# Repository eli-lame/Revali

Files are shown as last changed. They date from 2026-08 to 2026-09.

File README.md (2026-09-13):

# Revali

Flight controller firmware for a **hopcopter** — a quadrotor with a passive
spring-loaded telescopic leg that lets it hop along the ground instead of
flying continuously. Hopping is dramatically more power-efficient than hover,
because thrust is applied in short bursts at launch rather than held constantly.

The design replicates the Hopcopter described in *Science Robotics* (City
University of Hong Kong / HKUST): the leg is entirely passive — rubber bands
and a sliding rod — and **all** control authority comes from the four rotors.
The firmware's job is to keep the vehicle upright and steer it by tilting,
whether it is hovering, ballistic, or compressing on the ground.

## Hardware

| Role | Part |
|---|---|
| Vehicle MCU | ESP32-WROOM |
| IMU | SparkFun ICM-20948 (accel + gyro + mag) |
| Height / ground contact | 2× VL53L0X ToF, both downward-facing, spaced apart |
| Propulsion | 4× brushless motors + ESCs, quad-X layout |
| Controller MCU | ESP32-WROOM (offboard, USB-powered from the laptop) |
| Input (reference) | 1× SparkFun analog joystick (VCC, XOUT, YOUT, SEL, GND) |
| Input (optional) | DS4 / SCUF gamepad paired to the offboard ESP32 (Bluepad32) |
| Link | ESP-NOW |
| Ground station | Browser dashboard, fed over the controller's USB cable |

The controller sends **intent** — desired roll / pitch / yaw-rate / climb-rate
— never raw throttle; altitude and hop energy are managed onboard, and the
vehicle clamps every command to its own limits. Because the wire packet carries
intent, the vehicle is **controller-agnostic**: the reference one-stick joystick
(which cycles what its two axes mean) and an optional two-stick DS4/SCUF gamepad
(which needs no cycling) feed the identical packet. See
[flight_modes.md](docs/flight_modes.md) and
[communication.md](docs/communication.md).

## Repository layout

```
firmware/     PlatformIO project — vehicle (flight controller)
controller/   PlatformIO project — offboard transmitter
shared/       Link protocol definitions included by both projects
groundstation/ Host bridge + browser dashboard
docs/         Design documents
tools/        Host-side scripts (log decoding, PID tuning, plotting)
```

## Documentation

Start with [architecture.md](docs/architecture.md), then
[hardware.md](docs/hardware.md).

| Doc | Covers |
|---|---|
| [architecture.md](docs/architecture.md) | Module boundaries and data flow |
| [hardware.md](docs/hardware.md) | Wiring, buses, pin map, the VL53L0X address problem |
| [hardware_roadmap.md](docs/hardware_roadmap.md) | Board architecture, the 4-in-1 stack, staged path to a custom FC |
| [data_model.md](docs/data_model.md) | The structs every module shares |
| [estimator.md](docs/estimator.md) | Attitude fusion and dual-ToF height |
| [control_loop.md](docs/control_loop.md) | Controller, mixer, motor output |
| [flight_modes.md](docs/flight_modes.md) | State machine; per-controller intent resolution |
| [hop_mode.md](docs/hop_mode.md) | Hop phase machine and thrust profile |
| [communication.md](docs/communication.md) | ESP-NOW link, packet format, failsafe |
| [ground_station.md](docs/ground_station.md) | Browser dashboard for live telemetry and health |
| [safety.md](docs/safety.md) | Every failsafe and its trip condition |
| [scheduler.md](docs/scheduler.md) | Task rates and timing budget |
| [current_devtasks.md](docs/current_devtasks.md) | **The build order — start here to work** |

## Status

Early. The shared data contracts and estimator interfaces exist and compile;
no driver, controller, or link is implemented yet. See
[current_devtasks.md](docs/current_devtasks.md).

## Building

```bash
cd firmware && pio run -t upload && pio device monitor
```

## License

See [LICENSE](LICENSE).

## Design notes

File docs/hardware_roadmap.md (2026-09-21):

# Hardware roadmap

[hardware.md](hardware.md) describes the vehicle as it is wired **today**: an
ESP32-WROOM devkit, a SparkFun ICM-20948 breakout, two VL53L0X breakouts, four
discrete 30 A ESCs, and a buck module, all joined by roughly fifty wires. That
arrangement is correct and it works. It is also most of the vehicle's dry mass
that is not a motor, and on a machine whose entire premise is that launch
energy is scarce, that matters.

This document records how the electronics get from there to a custom board, in
what order, and — more importantly — which things deliberately do **not** get
integrated. It is the design-rationale companion to `hardware.md`: that file
says what to wire, this one says why the board looks the way it does.

---

## The central decision: two boards, not one

The intuitive move is a single custom board carrying everything — MCU, IMU,
buck, battery sense, and the motor power distribution. **Do not do that.** The
vehicle gets two boards:

```
        +------------------------------+
        |  REVALI FC  (custom)         |  MCU, IMU, 5 V buck, 3V3 LDO,
        |  30.5 x 30.5 mounting        |  battery divider, USB, connectors
        +--------------+---------------+
                       |  8-pin JST-SH ribbon
                       |  VBAT . GND . S1-S4 . current sense . telemetry
        +--------------+---------------+
        |  4-IN-1 ESC  (off the shelf) |  four ESCs + power distribution,
        |  30.5 x 30.5, 3-6S, 45-60 A  |  battery leads and 12 phase wires
        +------------------------------+
```

The 4-in-1 ESC **is** the power distribution board. It is not an extra
component sitting alongside a PDB; it is the PDB, with the four speed
controllers already integrated, the bulk capacitor already placed next to the
FETs, and the current shunt already installed.

### Why the motor current does not come onto our board

It is tempting to reason that since VBAT is already present for the buck, the
motor rails may as well come too. The voltage is the same. The current is not:

| Path | Current at 14.8 V |
|---|---|
| Buck feed (5 V @ 1 A out, ~85 % efficient) | **~0.4 A** |
| Four ESCs at peak | **~120 A** |

That is a factor of three hundred, and it changes the problem completely.

**Copper.** At 2 oz, carrying 120 A needs roughly **44 mm of copper width**
even allowing a punishing 45 °C temperature rise — wider than the whole board.
A 60 A launch burst still needs ~17 mm, per path, in four directions. This is
why commercial PDBs are effectively busbars: solid pours with the soldermask
removed so solder can be flooded on to add metal by hand.

**di/dt.** ESCs switch at 24–48 kHz with sharp edges, and each one needs a
low-ESR capacitor within about 5–10 mm of its power pads. Long pours from a
central battery pad out to four corner ESCs add loop inductance, and that
inductance produces voltage spikes that destroy FETs. It is the most common way
a home-made PDB kills bought ESCs — and it kills them in a way that looks like
the ESCs were faulty.

**Ground bounce.** 120 A of pulsed 30 kHz current sharing copper with a 3.3 V
SPI bus and a gyro read at 1 kHz is a noise problem that commercial designs
avoid by putting power and flight control on separate boards.

**Thermal.** 120 A through even 1 mΩ of copper is 14 W. That board becomes a
heater sitting under the IMU, and gyro bias drifts with temperature.

**Blast radius.** Lift a pad soldering 14 AWG battery leads and you have
destroyed the MCU, the IMU and the buck along with it. Separate boards mean a
dead power stage is a thirty-dollar replacement, not a respin and a three-week
wait.

### It is also the lighter option

A custom PDB does not remove the twelve motor phase wires, and it leaves four
ESC bricks on the arms. A 4-in-1 removes the bricks and shortens the phase
wires to a couple of centimetres each.

| | Discrete ESCs + custom PDB | 4-in-1 |
|---|---|---|
| ESC mass | ~7 g × 4 = 28 g | 12–14 g total |
| PDB mass | 8–12 g (2 oz copper) | 0 — it is the PDB |
| Phase wire | full arm length × 12 | ~2 cm × 12 |
| FC ↔ power interface | 16 wires | one ribbon |

Roughly **25–30 g saved**, which is the thing we were trying to buy in the
first place.

### What our board keeps

Everything that made a custom board attractive, minus the copper:

- MCU and IMU as chips/modules rather than breakouts
- 5 V buck **on our board**, fed from VBAT up the ribbon
- Battery divider tapping **raw** VBAT before regulation, as
  [hardware.md](hardware.md) requires — the buck hides the sag the failsafe
  needs to see
- USB, status LED, buzzer, connectors

Do not take 5 V from an ESC BEC even when one is present. `hardware.md` already
states the rule — motor current transients on a shared 5 V rail cause brownouts
that look exactly like firmware crashes — and a BEC on the ESC board sits in
the middle of the switching it would need to be immune to.

### The ESC interface — Skystars KO50A

The 4-in-1 selected for Stage 1. Confirmed specifications:

| | |
|---|---|
| Board / mounting | 41 × 46 mm, 30.5 × 30.5 M3, soft-mounts included |
| Weight | 13.3 g |
| MCU / firmware | BB21 @ 48 MHz, BLHeli_S 16.x, DShot150/300/600 |
| Pack | 3–6 S (silkscreened 25 V — **stay on 4 S**, 6 S at full charge is 25.2 V) |
| Current sensor | Yes |
| **BEC** | **No** — the 5 V rail is ours to generate |
| In the box | ESC, 8-pin cable, bulk capacitor |

The 8-pin JST-SH pinout, confirmed against the hardware:

| Pin | Signal | Goes to |
|---|---|---|
| 1 | GND | board ground |
| 2 | **BAT** | raw pack voltage → buck input and battery divider, nothing else |
| 3 | S1 | motor 1 signal |
| 4 | S2 | motor 2 signal |
| 5 | S3 | motor 3 signal |
| 6 | S4 | motor 4 signal |
| 7 | **NC** | not connected — no separate telemetry line on this board |
| 8 | CURR | analog current-sense output → ADC1 |

Two things follow. **BAT is raw pack voltage**, 16.8 V at full charge on 4 S — it
goes to the buck input and the divider and nowhere else. In particular it must
never reach the devkit's `VIN` pin, whose onboard AMS1117 is rated to roughly
15 V.

And pin 7 being NC means there is **no separate ESC telemetry wire**. That does
not rule out RPM feedback: bidirectional DShot returns telemetry on the signal
line itself, so flashing Bluejay onto the BLHeli_S firmware gets RPM back over
S1–S4 with no extra conductor.

---

## Power topology and the on/off switch

There is exactly **one battery connection in the vehicle**: the XT60 solders to
the 4-in-1's battery pads, alongside the bulk capacitor. Nothing high-current
ever reaches our board.

```
  LiPo ──XT60──► 4-IN-1 battery pads (B+ / B-)
                    |
                    +--> internally: the four ESCs
                    |
                    +--> 8-pin ribbon: BAT, GND --> REVALI FC
                                                      |
                                                      +--> [FC power switch]
                                                             |
                                                             +--> buck --> 5 V --> devkit VIN
                                                             +--> 100k/22k divider --> ADC1
```

### There is no switch in the motor path, and there will not be one

The v1 prototype schematic placed a screw terminal in series with battery
positive, annotated "switch goes here." That is deleted, for two reasons.

**A switch there carries full motor current** — roughly 120 A peak. A switch
genuinely rated for that is a contactor: heavier than everything else on the
board put together, and it inserts contact resistance into the highest-current
path in the vehicle.

**Moving it to the FC does not achieve the same thing.** A switch that only
cuts our board's BAT feed leaves the ESCs fully powered from the pack. This is
not especially *dangerous* — DShot frames are checksummed and BLHeli will not
arm without a valid throttle-low signal, so floating inputs on an unpowered FC
do not spin motors — but it disconnects nothing that matters, while looking
like it does.

**The battery connector is the disconnect.** No FPV multirotor has a power
switch. Unplugging the XT60 is the only guaranteed-safe state, and an
anti-spark XT60 handles the inrush spark from the ESC's bulk capacitor.

### Power states

| State | How to get it | Motors |
|---|---|---|
| Fully off | XT60 unplugged | dead |
| FC only — bench work, flashing | USB connected, **no pack** | physically dead |
| Full system, safe | XT60 plugged in, firmware disarmed | live bus, held at disarmed value |
| Full system, armed | Safety arms — see [safety.md](safety.md) | live |

The second row is the important one: the devkit's USB gives a better
"controller running, motors physically dead" mode than any switch, for free.
That is the normal bring-up configuration.

### If a switch is fitted anyway

A small switch in the FC's BAT feed — downstream of the ribbon entry, upstream
of both the buck and the divider, so the whole board goes dead with no standby
drain — is a legitimate bring-up convenience: it power-cycles the FC for
reflashing without unplugging the pack. That path carries ~0.4 A at 16.8 V, so
any slide switch or even a removable 2-pin jumper is sufficient.

Label it in the schematic as **`FC POWER — NOT A SAFETY DISCONNECT`**. It is
not one, and in three months that label is the only thing that will say so.

---

## The ToF sensors stay off the board

This is a real constraint, not a convenience. [hardware.md](hardware.md)
requires each VL53L0X to sit at a recorded position in the body frame, with a
measured baseline between them, a known offset from the CG, and a clear ~25°
cone below it containing no part of the airframe. Front-left and rear-right of
the CG, spaced as widely as the frame allows — the baseline is what turns their
difference into a ground slope, and a short baseline makes the estimate noisy.

A sensor soldered to a 36 mm board is at the CG with a baseline of a few
centimetres. The FC gets a **4-pin JST-SH connector per sensor**; the sensors
mount where the geometry needs them.

The IMU is the opposite case: it belongs at the CG, on the board, soft-mounted.

---

## Staging

Two goals are in tension here: learning PCB design, and finishing the vehicle.
They conflict because a board revision is slow — about two weeks to design, two
to fabricate and ship, and first boards usually need one respin. That is
roughly seven weeks before working hardware exists. **If the firmware is
blocked behind the board, that cost lands on the whole project.**

So the tracks are kept independent. Each stage below flies on its own.

### Stage 0 — current: breadboard (done)

WROOM devkit, ICM-20948, two VL53L0X, discrete ESCs. Ugly, working. Firmware
development proceeds here and is never blocked by the board.

### Stage 1 — 4-in-1 ESC swap

Replace the four discrete ESCs and their harness with one 4-in-1. No PCB work.
This alone removes most of the wiring mass and validates the ribbon interface
the custom board will mate to.

### Stage 2 — carrier board

A **2-layer, hand-solderable** board on the 30.5 × 30.5 mounting pattern,
carrying the existing devkit in a 2.54 mm socket, the breakout modules, the
regulator, the battery divider, and the connectors. No bare chips, no fine
pitch, nothing that cannot be reworked with an iron.

**Built and routed; outline came out at 58 × 88 mm.** Bigger than a
conventional FC because a 30-pin devkit is 52 × 25 mm on its own, so the board
overhangs the ESC on every side. Acceptable at this stage — weight optimisation
is Stage 3's job, and it gets there by dropping the devkit for a bare module.

Ground is a **single plane on `B.Cu`** with no top pour. The top layer routed
densely enough that a pour filled only in patches and was not reaching several
of the pads it was meant to serve. Every ground connection is explicit instead:
through-hole pads through their own barrels, every SMD ground pad through a
short wide stub to its own via. That is best practice regardless of whether a
top pour exists — the return current from a decoupling capacitor wants the
shortest loop into the plane, not a wander across the top layer looking for a
via.

Full net-by-net spec, BOM and bring-up order:
[stage2-carrier/README.md](https://github.com/eli-lame/Genli/blob/main/stage2-carrier/README.md).

This stage is easy to skip and should not be. It is cheap and quick, it teaches
the entire pipeline end to end — schematic, footprints, layout, DRC, Gerbers,
ordering, assembly, bring-up — with almost nothing at stake, and every
schematic block and footprint it produces is reused by Stage 3. It also solves
the wiring problem immediately: roughly fifty wires become about six.

### Stage 3 — integrated FC

4-layer, assembled by the fab, bare module + IMU chip + integrated buck +
USB-C. Designed as a **drop-in replacement** for Stage 2: same pin functions,
same connector positions, same firmware binary.

Built this way, Stage 3 is optional. If it works, it goes in the vehicle. If it
does not, the vehicle still flies on Stage 2 hardware, and the project is not
hostage to a PCB revision.

---

## Link: ESP-NOW now, ELRS later

The eventual target is the standard split used by serious builds:

- **Control in** — ExpressLRS receiver over CRSF on a UART. Sub-5 ms, real link
  statistics, proper failsafe, telemetry on the return path.
- **Telemetry out** — BLE or USB to the ground station.

We are **not** switching yet. ESP-NOW works today, the vehicle's link layer is
already built around it, and Stages 1–3 already change the power architecture,
the board, and the mechanical layout. Changing the radio at the same time means
that when something misbehaves there is no way to tell which change caused it.

Note that BLE is not a candidate for the *control* link regardless — its
minimum connection interval is 7.5 ms with real jitter, and it is not designed
for deterministic control. BLE is for telemetry and configuration only, which
is exactly how commercial flight controllers use it.

**The one thing to do now:** put a 4-pin JST-SH footprint (5 V, GND, TX, RX) on
a spare UART on both the Stage 2 and Stage 3 boards, wired and unpopulated.
Four pads and about thirty cents. With them, adopting ELRS later is a firmware
change. Without them, it is a board respin.

When the switch does happen, two consequences follow. The `controller/` project
leaves the critical path — CRSF carries the same intent the wire protocol in
[communication.md](communication.md) already defines, so the vehicle stays
controller-agnostic and the custom transmitter becomes an optional input rather
than a dependency. And [ground_station.md](ground_station.md) loses its current
transport: the dashboard is fed over the controller's USB cable today, and
would instead talk to the vehicle directly.

---

## Part selection

| Block | Part | Why |
|---|---|---|
| 4-in-1 ESC | **Skystars KO50A** — 30.5 × 30.5, 3–6 S, 50 A | Ordered. Full interface above |
| 5 V regulator | **Pololu D24V10F5** — 5.1–36 V in, 5 V @ 1 A, 12.7 × 17.8 mm | Ordered. Fixed output, solder flat, 33 µF+ electrolytic at VIN per Pololu's lead-length warning |
| MCU | ESP32-WROOM-32E (bare module) | Same silicon as the devkit — zero firmware port. Castellated and hand-solderable |
| MCU (upgrade) | ESP32-S3-WROOM-1 | Native USB and BLE 5. Only worth it once BLE telemetry is wanted; verify the footprint difference before assuming drop-in |
| IMU | **ICM-42688-P** | Much better anti-alias filtering than the ICM-20948, which matters a great deal on a vehicle that repeatedly slams into the ground. Drop the magnetometer — it is useless indoors beside 120 A of motor current |
| ToF | **VL53L1X** | Programmable region of interest, which directly attacks the wide-cone problem documented in [hardware.md](hardware.md). VL53L5CX (8 × 8 zones) if off-axis rejection needs to be done properly |
| 5 V rail (Stage 3) | Discrete synchronous buck IC rated **≥ 36 V input** | Replaces the module once switching layout is worth learning on its own |
| 3.3 V rail | Stage 2: the devkit's onboard AMS1117 (~50 mA of sensors — ample). Stage 3: an LDO from 5 V, separate feed for the IMU | Low noise for the gyro |
| Protection | TVS on VBAT + low-ESR bulk at the pads | Non-negotiable beside brushless motors |

**On ESC voltage rating:** a "6–18 V" (2–4 S) part is not acceptable here. A 4 S
pack is 16.8 V at full charge, leaving 1.2 V of margin, and ESCs generate
regenerative spikes when throttle drops sharply. On a hopper that is not an
edge case — it is every single cycle: full-send launch, immediate cut,
ballistic phase, catch on landing. Specify 3–6 S (≈26 V, 35 V capacitors).

Choose every part against the fab's assembly library **before** finalising the
schematic. On a board this size, hand-soldering an LGA IMU is miserable; part
availability will constrain the BOM more than preference does.

---

## Rules specific to a hopping vehicle

This airframe's purpose is repeated hard impact, which changes the board rules:

- No tall electrolytics standing unsupported. Solid polymer capacitors, and
  stake anything with mass.
- Soft-mount the board on gummies or TPU standoffs. A rigidly-mounted gyro on
  this vehicle sees impact spikes that alias into the attitude estimate.
- Prefer solder pads and staked wires anywhere a connector could walk out of
  its housing under shock.
- Conformal coat after bring-up.
- Buy spares. Two ESCs, a spare MCU, and many propellers — this machine is
  designed to hit the ground.

---

## Defects in the v1 prototype schematic

Recorded here because they are cheap to fix now and expensive to find during
bring-up. That board has not been fabricated and is superseded by the staging
above, but the same nets carry forward.

**ESC signal numbering is reversed relative to the pin map.** The schematic
assigns `ESC1_SIG → GPIO14, ESC2 → GPIO27, ESC3 → GPIO33, ESC4 → GPIO32`. The
pin map in [hardware.md](hardware.md) assigns Motor 1 (front-left) to GPIO 32,
Motor 2 to 33, Motor 3 to 27 and Motor 4 to 14 — so schematic `ESC1` is the pin
map's Motor 4, and the ordering is inverted end to end. The mixer would drive
the wrong physical motor for every roll and pitch term. Combined with the
unresolved yaw-sign question from the pusher-prop mounting, this would be very
difficult to diagnose in the air. One of the two must change;
[hardware.md](hardware.md) is the source of truth.

**Battery sense is absent.** GPIO 34, 35, 36 and 39 are all marked no-connect.
The 100 kΩ / 22 kΩ divider specified in `hardware.md` is not on the board, so
`warn_voltage`, `land_voltage` and `critical_voltage` in [safety.md](safety.md)
have no input and the low-battery failsafe cannot function. Two resistors and a
capacitor on a board that already carries VBAT.

**No bulk capacitance, TVS, or reverse-polarity protection on VBAT.**
Acceptable while every power component is a module with its own input caps; it
becomes ours the moment the buck is on our board.

---

## Open decisions

- **Frame geometry.** Motor-to-motor diagonal, and confirmation that the leg's
  travel clears a centre-mounted stack. The leg moves below the frame and does
  not pass through it, so a centred stack is expected to be fine — this needs
  checking against the actual frame before layout.
- **MCU for Stage 3** — WROOM-32E (no port, no BLE) or S3 (port, BLE).
  Deferred until the BLE telemetry path is actually wanted.
- **Current sensing.** Deferred, not dropped. The KO50A exposes `CURR` on pin 8,
  and it would give joules-per-hop directly — the number that validates the
  efficiency premise this whole vehicle is built on. Stage 2 routes the trace
  and leaves the resistor unpopulated, so enabling it later costs one 0805 part
  plus a calibration. Two things are unresolved until then: the full-scale
  output voltage, which Skystars does not publish and which must be measured
  before anything is connected to a GPIO, and the volts-per-amp scale factor,
  which needs a meter.

Settled since this document was written: the KiCad projects live in a separate
repository, **[eli-lame/Genli](https://github.com/eli-lame/Genli)** — boards
only, one KiCad project per board, with v1 archived there as `v1-prototype/`
and the current work in `stage2-carrier/`. Its README carries the layout and
library conventions.

Because the boards and the firmware are versioned separately, two rules apply.
This repository keeps [hardware.md](hardware.md) as the sole pin map and Genli
links to it rather than copying it. And when gerbers are generated, the Revali
commit the board was designed against is recorded in that board's
`production/` directory — it is the only link back from a fabricated board to
the pin map it assumed.

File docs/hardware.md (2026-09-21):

# Hardware

This file describes the vehicle as it is wired today, and is the source of
truth for the pin map. For where the electronics are *going* — the two-board
stack, why motor current stays off our board, and the staged path to a custom
FC — see [hardware_roadmap.md](hardware_roadmap.md).

## Vehicle

| Function | Part | Bus | Notes |
|---|---|---|---|
| MCU | ESP32-WROOM-32 | — | 240 MHz dual core |
| IMU | SparkFun ICM-20948 | **SPI** | accel + gyro @ 1 kHz, AK09916 mag @ ~100 Hz |
| Height A | VL53L0X | I2C | downward, front-left of CG |
| Height B | VL53L0X | I2C | downward, rear-right of CG |
| Motors | 4× brushless + ESC | LEDC/RMT | quad-X |
| Battery sense | resistor divider | ADC1 | ADC2 is unusable when WiFi/BT is active |

### Put the IMU on SPI, not I2C

The ICM-20948 breakout ships configured for Qwiic/I2C, but the control loop
needs it at 1 kHz. A 12-byte burst read at 400 kHz I2C costs roughly 700 µs of
bus time including addressing and ACKs — about **70 % of a 1 ms tick**, on a bus
also shared with two ranging sensors. That does not fit.

The same read over SPI at 7 MHz costs ~16 µs. Cut the `I2C`/`SPI` select jumper
on the SparkFun board and wire the SPI pads.

If you must stay on I2C for bring-up, run the loop at 500 Hz and put the ToF
pair on the second I2C peripheral. Treat that as temporary.

### Both VL53L0X sensors boot at address 0x29

This is the single most common way this build fails, so handle it first. Every
VL53L0X powers up at `0x29`, and the address is **not** persistent — it resets
on every power cycle. With both on one bus and no mitigation, you get a garbage
mixture of the two.

Wire each sensor's `XSHUT` pin to its own GPIO and sequence them at boot:

1. Drive **both** XSHUT low — both sensors held in reset, bus is clear.
2. Release XSHUT A. Wait ~2 ms for boot.
3. `setAddress(0x30)` on the sensor now answering at `0x29`.
4. Release XSHUT B. Wait ~2 ms. It comes up at `0x29`.
5. Verify: A responds at `0x30`, B at `0x29`, and a bus scan shows exactly two.

Never skip step 5 — a silent failure here reads one sensor twice and the
ground-plane estimate becomes meaningless while looking perfectly plausible.

XSHUT is **not** 5 V tolerant and has an internal pull-up; drive it from a GPIO
directly, and note that some breakouts need the pin driven low rather than
floated to actually hold reset.

**"Release" means high-impedance, not driven high.** On the carrier boards in
use here, XSHUT is pulled up by a 47 kΩ resistor to the breakout's internal
**2.8 V** rail — not to 3.3 V. So steps 2 and 4 above should set the GPIO back
to `INPUT` and let that resistor do the work. Driving the pin high instead
pushes a 3.3 V output into a 2.8 V rail through 47 kΩ; it works, but it
back-feeds current for no reason, and there is nothing to gain from it.

### The ToF breakout's VCC must be 3.3 V, never 5 V

The carrier boards have an onboard regulator and a MOSFET level shifter, so
`VIN` will happily accept 5 V — **do not give it 5 V.** The breakout's I2C
pull-up resistors (10 kΩ) connect to `VIN` itself, so the SDA and SCL lines
sit at whatever `VIN` is. Feed it 5 V and 5 V arrives on GPIO 21 and 22, which
are not 5 V tolerant.

This is why the pin map below says 3V3 for ToF VCC. It is not a convention;
it is the difference between a working bus and a damaged ESP32.

Those same 10 kΩ resistors are also why **no I2C pull-ups are needed on the
carrier board** — two breakouts on one bus put two 10 kΩ sets in parallel,
about 5 kΩ, which is already in the right range.

### Sensor geometry matters

Record the mounting position of each ToF in the body frame — the estimator
needs the baseline distance between them to turn their difference into a ground
slope, and needs each sensor's offset from the CG to correct for the height
change caused by tilt. Put these in `Parameters`, not in code comments.

Also record the **leg length**: the distance from each ToF to the foot when the
leg is fully extended. That number is the touchdown threshold.

### The VL53L0X measures a cone, not a point

It's a laser (VCSEL) source, but the optics spread it to a **~25° full field of
view** (~±12.5° off boresight), and the receiver's field of view is similarly
wide. The sensor reports the closest/strongest return **anywhere in that
cone**, not a single point straight down. Treat it like a narrow flashlight
beam, not a laser pointer.

The cone's footprint grows with distance:

```
footprint_diameter ≈ 2 × height × tan(12.5°)
```

At 100 mm of height that's already ~44 mm across. Anything within that
footprint — a wall, a bench edge, part of the airframe itself — can be
reported instead of the ground, with no flag that it happened; the reading
just looks like a slightly-wrong but plausible number.

This is a real mounting constraint, not just a bench-test nuisance:

- Each ToF needs a clear ~25° cone below it, out to at least the maximum
  expected hop height, with **nothing else on the airframe** — legs, arms,
  the other ToF's mount — inside that cone.
- During bring-up, test over open floor. A wall or bench edge within roughly
  a footprint-radius of the sensor's boresight, at your test height, will
  contaminate the reading.
- Task `[2.9]`–`[2.11]` in [current_devtasks.md](current_devtasks.md) should
  include physically checking this cone against the frame, not just measuring
  baseline/offset/leg-length in isolation.

### Pin map — vehicle ESP32

This is the pin assignment used throughout this project and by every doc that
references a GPIO number. Wire to it exactly. If you need to deviate (a board
revision, a part you're substituting), update this table first and treat every
other mention of these pins elsewhere in the docs as needing a matching update.

| Signal | GPIO | Wire color (suggested) | Notes |
|---|---|---|---|
| IMU SCLK | 23 | yellow | **not a VSPI default** — see the note below |
| IMU MISO | 25 | green | **not a VSPI default** |
| IMU MOSI | 19 | blue | **not a VSPI default** |
| IMU CS | 15 | orange | strapping pin, but its internal pull-up holds CS deasserted at boot — see below |
| IMU INT | 35 | white | data-ready interrupt — use it, don't poll. Input-only pin; see the note below |
| IMU VCC | 3V3 | red | **not 5 V** |
| IMU GND | GND | black | |
| I2C SDA | 22 | brown | ToF pair, 400 kHz, shared bus. **Not the Arduino default** |
| I2C SCL | 21 | gray | ToF pair, 400 kHz, shared bus. **Not the Arduino default** |
| ToF A XSHUT | 18 | violet | front-left sensor |
| ToF B XSHUT | 26 | pink | rear-right sensor |
| ToF VCC (both) | 3V3 | red | **not 5 V** — the breakout pulls SDA/SCL up to VIN |
| ToF GND (both) | GND | black | |
| Motor 1 (front-left) | 32 | — | ESC signal, LEDC or RMT |
| Motor 2 (front-right) | 33 | — | ESC signal |
| Motor 3 (rear-right) | 27 | — | ESC signal |
| Motor 4 (rear-left) | 14 | — | ESC signal |
| Battery sense (divider midpoint) | 34 | red/black twisted pair | ADC1, input-only pin |
| Status LED | 2 | — | onboard, no external wiring |
| *free* | 4, 5 | — | full-function pins, unassigned |
| Arming buzzer | 13 | — | optional but recommended |
| ELRS / CRSF TX (FC → receiver) | 16 | — | reserved, unpopulated — see below |
| ELRS / CRSF RX (receiver → FC) | 17 | — | reserved, unpopulated |

**ELRS is reserved, not in use.** The link is ESP-NOW for this hardware
generation — see [communication.md](communication.md). The Stage 2 board carries
a four-pin footprint on these two GPIOs so that adopting CRSF later is a
firmware change rather than a board revision. Nothing is populated, and no
firmware should assume a receiver is present.

The direction is named **from the ESP32's point of view**: GPIO 16 is the FC's
transmit and connects to the *receiver's* RX; GPIO 17 is the FC's receive and
connects to the receiver's TX. Getting that crossover backwards is the standard
UART mistake, and it will not be discovered until someone first plugs a receiver
in months from now.

These pins are not fixed by hardware. The ESP32 routes UART through its GPIO
matrix, so any output-capable pin can serve — GPIO 16/17 are simply the Arduino
core's defaults for `Serial2`. If they move, this table changes first. Note also
that GPIO 16/17 are consumed by PSRAM on ESP32-WROVER modules; the WROOM-32 used
here is unaffected, but a future module with PSRAM would not be.

**Every SPI pin and both I2C pins are off their framework defaults — so they
must be named explicitly in firmware.**

```cpp
SPI.begin(23, 25, 19, 15);   // sck, miso, mosi, ss
Wire.begin(22, 21);          // sda, scl
```

**None of these four SPI pins and neither I2C pin is a framework default.**
Bare `SPI.begin()` or `Wire.begin()` calls will silently use the wrong pins:
the default clock would land on GPIO 18, which now resets a ToF, and the
default I2C assignment has SDA and SCL crossed relative to this board. In both
cases nothing errors — the sensors simply never answer, which reads as dead
hardware rather than a firmware assumption.

Watch the argument order too. `SPI.begin` takes **sck, miso, mosi, ss**;
`Wire.begin` takes **sda, scl**. Transposing either pair produces the same
silent failure.

None of it costs anything measurable. SPI signals on non-default pins route
through the ESP32's GPIO matrix rather than the IOMUX, lowering the maximum SPI
clock from 80 MHz to 40 MHz and adding ~25 ns of input delay on MISO; this bus
runs at 7 MHz. It is all-or-nothing, incidentally — moving one signal off its
default puts the whole bus on the matrix, so further shuffling between
non-default pins is free. I2C is routed through the same matrix and has no
preferred pins at all.

The assignments came out of routing the Stage 2 board. The first move was
taking SCLK off GPIO 18 so the two ToF XSHUT lines could sit on opposite pin
rows, matching their connectors being on opposite edges; the rest followed.

One layout consequence: the clock is physically separated from MISO, MOSI and
CS. At 7 MHz the resulting skew is a fraction of a nanosecond against a 71 ns
half-period, so it does not matter — but do not run SCLK closely parallel to an
ESC signal for any distance, since both are high-activity lines. Cross them at
right angles.

**CS is on GPIO 15, a strapping pin, and that is deliberate rather than
tolerated.** GPIO 15 must be high at boot (low merely silences the ROM boot
log), and it has an internal pull-up. SPI chip-select is active-low, so that
pull-up holds the IMU *deselected* through reset and before firmware configures
the pin — the safe state — while satisfying the strapping requirement as a side
effect. The pin's quirk and the signal's idle level agree.

The one thing that would break it: never add anything that pulls GPIO 15 low at
boot. The IMU's CS input is high-impedance and will not, and there is no
pull-down on the Stage 2 board.

**IMU INT is on GPIO 35, which is input-only and has no internal pull.**

That is a deliberate trade: the interrupt line is only ever an input, so it
costs nothing to spend one of the input-only pins on it, and GPIO 4 stays free
as a full-function pin. The ESP32 supports external interrupts on any usable
GPIO, so being input-only is no obstacle.

Two consequences, both firmware's problem rather than the board's:

- GPIO 34–39 have **no internal pull-up or pull-down**, and it is not
  configurable. This is fine while the ICM-20948's INT output stays
  **push-pull**, which is its default. Do not reconfigure it to open-drain via
  `INT_PIN_CFG` — there is no pad for the external pull-up that would then be
  required.
- The pin **floats until the IMU initialises** and starts driving it. Attach
  the interrupt handler *after* IMU init completes, or startup noise on a
  floating input produces spurious interrupts that look like a sensor fault.

Motor numbering matches the mixer diagram in [control_loop.md](control_loop.md)
— wire ESC signal 1–4 to these GPIOs in that same front-left/front-right/
rear-right/rear-left order, or the mixer's roll/pitch/yaw math will not match
the physical motor it thinks it's driving.

**Avoid** GPIO 6–11 (flash), and be careful with 0, 2, 12, 15 (strapping). A
pull-up on GPIO 12 at boot bricks the boot voltage selection. **Also avoid
GPIO 1 and 3 (UART0 TX/RX)** for anything — they carry the USB serial
console every `Serial.print` in this project depends on, and the ROM
bootloader uses them to receive new firmware during flashing. Driving them
with anything else (an interrupt line, a sensor signal) conflicts with both.
Note this isn't an ADC-related restriction; ESP32 supports external
interrupts on essentially any usable GPIO, so a digital signal like IMU INT
just needs a pin outside this avoid-list, not an ADC-capable one.

### Props mount BELOW the arms (pusher configuration)

The motors hang under the arms with the props on the underside, rather than
sitting on top as on a conventional quad. The physics of flight are unchanged —
every multirotor pushes air down to rise — but three things follow from the
mounting, and all three are easy to get wrong silently.

**1. Prop handedness or motor direction must be flipped.** Inverting a
motor/prop assembly reverses which way the blades push air for the same
electrical rotation direction. Take a motor that produced upward thrust
mounted on top, invert it, and it now pushes air *up* and drives the vehicle
into the ground. Fix it one of two ways, not both:

- fit the opposite-handed prop (swap CW for CCW on each position), or
- reverse the motor by swapping any two of the three ESC phase wires.

Doing both cancels out and leaves you exactly where you started. Pick one
convention, write it down, and verify thrust physically — task `[2.14]`.

**2. The yaw sign in the mixer is likely inverted.** Roll and pitch are
unaffected: they come from differential thrust across the frame geometry, and
front-left is still front-left. But yaw comes from each rotor's *reaction
torque*, which depends on spin direction — so flipping the mounting flips the
relationship between "motor spins this way" and "vehicle yaws that way." Do
not assume the sign convention in [control_loop.md](control_loop.md) is
correct as written; verify it on the bench and flip the yaw terms if needed.

**3. Ground clearance is now a design constraint, not an afterthought.** The
props are the lowest part of the airframe apart from the leg, on a vehicle
whose entire purpose is to repeatedly slam into the ground. The leg must be
long enough that no prop can strike, **including on a tilted landing**:

```
leg_length  >  prop_bottom_offset  +  prop_radius_from_CG × sin(max_landing_tilt)
```

That inequality couples leg length to `hop_max_tilt` in
[hop_mode.md](hop_mode.md) — a longer leg buys more allowable landing tilt,
and a tilt limit set without checking this produces prop strikes on perfectly
"successful" hops. Measure both, do the arithmetic, and record the numbers in
`Parameters`.

**4. Keep the props out of the ToF cone.** The VL53L0X has a wide field of
view (roughly a 25° cone), and props mounted low sit much closer to the plane
the downward sensors look through. A blade clipping the edge of that cone
produces spurious short readings at blade-pass frequency — which the estimator
will happily interpret as the ground rushing up, or as a false ground contact
mid-hop. Mount both ToF sensors well inboard of the prop discs, and verify
with the motors spinning that the ranging output is clean.

### Battery sense wiring

For a 4S pack (14.8 V nominal, ~16.8 V full, ~12.0–13.2 V low cutoff): a
**100 kΩ / 22 kΩ** divider from raw battery+ to GND, tapped at the midpoint
into GPIO 34 (ADC1).

```
 Battery+ (raw) ──[100kΩ]──┬──[22kΩ]── GND
                            │
                            └── GPIO 34 (ADC1_CH6)
```

At full charge: `16.8V × 22/(100+22) ≈ 3.03V` — comfortably under the 3.3 V
ADC ceiling with margin for the nonlinearity noted above.

**Tap raw battery+, before the buck converter — not the buck's regulated 5 V
output.** The buck converter deliberately holds a steady output voltage
regardless of pack voltage, so it hides exactly the sag the low-battery
failsafe needs to see. Two separate wires off battery+: one through the buck
to power the board, one through this divider to the ADC. They must not share a
connection. Use 1% tolerance resistors — divider accuracy sets your voltage
accuracy directly, and this number is what `warn_voltage` / `land_voltage` /
`critical_voltage` in [safety.md](safety.md) are checked against.

Calibrate against a real meter once wired — task `[2.17]` in
[current_devtasks.md](current_devtasks.md).

### ESC and power

- ESCs must see a **valid idle signal before arming**. Boot with outputs at the
  disarmed value and hold there until Safety explicitly arms.
- Give the ESP32 its own regulator. Motor current transients on a shared 5 V
  rail cause brownouts that look exactly like firmware crashes.
- Common ground between ESP32, ESCs, and battery sense is not optional.
- **Remove the propellers** for every bring-up step until the task list says
  otherwise.

## Controller

| Function | Part | Connection |
|---|---|---|
| MCU | ESP32-WROOM-32 | — |
| Power | USB from the laptop | 5 V, via the dev board's onboard regulator |
| Input | SparkFun analog joystick | see below |

### USB power, and what it buys you

The controller is **USB-tethered to the laptop** rather than battery powered.
Two consequences worth designing around:

- **No battery sense on the controller.** It is not going to brown out
  mid-flight, so the low-battery failsafe applies only to the vehicle. The
  controller still needs to handle *the vehicle's* battery telemetry for its
  LED/buzzer, but has no pack of its own to monitor.
- **The USB cable is a free data channel.** It is already physically there for
  power, so it costs nothing to also stream everything the controller knows —
  its own stick state plus the telemetry it receives from the vehicle — up to
  the laptop over USB serial. That is exactly what the ground station in
  [ground_station.md](ground_station.md) is built on, and it is the reason the
  webapp needs no extra radio and no WiFi on the vehicle at all.

A tether is a real constraint on where you can stand while flying — plan the
flight area around cable length, or plan to switch the controller to a battery
and a USB-serial-over-radio bridge later. Note that going battery-powered
would mean rethinking how the ground station gets its data.

### Pin map — controller ESP32 (joystick)

Same rule as the vehicle table above: this is the definitive assignment, not a
suggestion. Applies to controller form 6a (reference joystick) only — the DS4
dongle (form 6b) has no joystick to wire and its own pin map is not yet
written (see [current_devtasks.md](current_devtasks.md) Phase 6).

| Joystick pin | ESP32 GPIO | Wire color (suggested) | Notes |
|---|---|---|---|
| VCC | 3V3 | red | **not 5 V** — ADC inputs are not 5 V tolerant |
| GND | GND | black | |
| XOUT | GPIO 36 (ADC1_CH0) | white | |
| YOUT | GPIO 39 (ADC1_CH3) | yellow | |
| SEL | GPIO 27 | green | active-low, needs `INPUT_PULLUP` |

Use **ADC1 only**. ADC2 is claimed by the radio and returns garbage whenever
the WiFi radio is active — which, on the controller, is always, since ESP-NOW
rides on it.

The SparkFun thumb joystick's `SEL` switch is a plain momentary contact to
ground with no debouncing. Debounce it in firmware (~20 ms) or a single click
will register as three mode changes.

The ESP32 ADC is nonlinear near both rails and does not read a true 0 or 3.3 V.
Calibrate: record the resting centre and both endpoints per axis, store them,
and apply a deadband around centre. Do not assume 2048 is centre — it usually
is not, and an uncalibrated centre becomes a constant tilt command.

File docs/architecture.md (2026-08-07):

# Architecture

Revali is the flight controller firmware for a single vehicle: a quadrotor
hopcopter with a passive spring leg. It is not a general-purpose framework and
carries no abstractions for vehicles it does not fly. Interfaces exist for
exactly two reasons: to let a module be tested with no hardware attached, and
to keep the control loop from depending on a sensor datasheet.

## Two processors

The vehicle always has a peer that turns human input into `CMD_CONTROL`
packets. There are two interchangeable forms of that peer, and **the vehicle
cannot tell them apart** — both send the identical intent packet (see
[communication.md](communication.md)):

**A — Reference joystick controller** (the replicable default):

```
   ┌──────────────────────────┐            ┌──────────────────────────────┐
   │   CONTROLLER  (ESP32)    │            │      VEHICLE  (ESP32)        │
   │                          │            │                              │
   │  Joystick ADC + button   │  ESP-NOW   │  Sensors → Estimator         │
   │        │                 │  ──────►   │      │                       │
   │  Interpret → intent      │  command   │  Setpoint → Controller       │
   │        │                 │   50 Hz    │      │                       │
   │  Link TX ────────────────┼──          │  Mixer → Motors → ESCs       │
   │  Link RX ◄───────────────┼──          │      │                       │
   │        │                 │  ◄──────   │  Safety (can veto anything)  │
   │  Status LED / buzzer     │ telemetry  │                              │
   └──────────────────────────┘   10 Hz    └──────────────────────────────┘
```

**B — Gamepad + ground dongle** (if you have a DS4-compatible controller):

```
   DS4 ──BT──► ┌───────────────────┐  ESP-NOW  ┌──────────────┐
   (gamepad)   │  DONGLE  (ESP32)  │ ────────► │   VEHICLE    │
               │  Bluepad32 pairs  │  command  │  (unchanged  │
               │  DS4, maps → intent│  50 Hz    │   from A)    │
               │        │          │ ◄──────── │              │
               │  Link  │  USB     │ telemetry └──────────────┘
               └────────┼──────────┘   10 Hz
                        ▼
                   LAPTOP (ground station, display-only)
```

In both forms the peer is **deliberately dumb about safety**. It reads input,
resolves it to intent (desired roll/pitch/yaw-rate/climb-rate), and ships it.
**Every decision that can hurt the vehicle is made on the vehicle** — arming,
command legality, tilt and height limits, failsafes. A controller that crashes,
browns out, or walks out of range must not be able to command anything unsafe,
and the vehicle must react correctly to it simply going silent.

What the peer is *not* dumb about is **interpretation**: turning sticks and
buttons into intent is device-specific (a one-stick joystick cycles modes to
fill four command fields; a two-stick gamepad fills them directly), so it lives
here, on the peer — never on the vehicle. That is the whole point of sending
intent rather than raw axes. In form B the dongle, not the laptop, generates
`CMD_CONTROL`: the flight-critical path is DS4 → dongle → vehicle, all
real-time hardware, and the laptop stays display-only per
[ground_station.md](ground_station.md).

## Vehicle data flow

```
        ICM-20948 (SPI, 1 kHz)          VL53L0X ×2 (I2C, ~50 Hz)      Battery ADC
                │                              │                          │
                ▼                              ▼                          ▼
            ImuData                        RangeData[2]              BatteryState
                └──────────────┬───────────────┘                          │
                               ▼                                          │
                        State Estimator                                   │
                 (Mahony attitude + height filter)                        │
                               │                                          │
                               ▼                                          │
                        VehicleState ─────────────────────────────────────┤
                               │                                          │
   ESP-NOW cmd ──► Mode Manager ──► DesiredState                          │
                        ▲      │                                          │
                        │      ▼                                          │
                        │   Controller (cascaded PID)                     │
                        │      │                                          │
                        │      ▼                                          │
                        │  ControlOutput  (torque + collective thrust)    │
                        │      │                                          │
                        │      ▼                                          │
                        │   Mixer (quad-X)                                │
                        │      │                                          │
                        │      ▼                                          │
                        │  MotorOutput                                    │
                        │      │                                          │
                        │      ▼                                          │
                        │  Motor Manager ──► ESCs                         │
                        │      ▲                                          │
                        └──────┴───────── Safety ◄─────────────────────────┘
                                    (arms, disarms, clamps, kills)
```

Safety sits **downstream of everything** and holds a veto. It can force
`MotorOutput` to idle or zero regardless of what the controller wanted, and it
can force the Mode Manager into `FAILSAFE`. No other module may write motor
outputs directly.

## Modules

| Module | Owns | Must not know about |
|---|---|---|
| **HAL** | GPIO, SPI, I2C, LEDC/RMT, ADC, timers | Anything about flight |
| **Drivers** | ICM-20948, VL53L0X, ESC output, battery sense, LEDs | Estimation or control math |
| **Estimator** | Attitude fusion, height fusion, ground-plane slope | Which chip produced a sample |
| **Mode Manager** | The flight state machine; scaling/clamping incoming intent into `DesiredState` | How input was interpreted, PID internals |
| **Hop Sequencer** | The hop phase machine and thrust profile | Motor wiring |
| **Controller** | Cascaded angle→rate→torque PID, altitude PID | Motor count or layout |
| **Mixer** | Quad-X allocation, saturation handling | Vehicle state |
| **Motor Manager** | Arming, idle, ESC protocol, output ordering | Why it was told to stop |
| **Link** | ESP-NOW transport, framing, CRC, sequence, timeout | What a command means |
| **Safety** | Every failsafe, the kill path | How to fly |
| **Parameters** | Persisted tuning values (NVS), defaults | Who consumes them |
| **Logging** | Ring buffer, flush, telemetry framing | Everything (read-only) |

## Layering rule

Dependencies point one direction only:

```
HAL ◄── Drivers ◄── Estimator ◄── Controller/Mixer ◄── Mode Manager
                         ▲                                  ▲
                         └──────── Safety ──────────────────┘
                                      ▲
                                     Link
```

A lower layer never includes a higher one. `Controller` includes
`core/types.h` and nothing else from the vehicle. This is what allows the PID
and mixer to be compiled and tested on a host machine with no ESP32 present —
which is how they will actually be tuned before the first flight.

## Why interfaces exist here

Only three interfaces are justified, and each earns its keep:

- **`IImuSource`** — lets the fusion filter run against recorded or synthetic
  samples on a host, and lets a bench build inject a fake IMU.
- **`IStateEstimator`** — lets the controller be exercised against a scripted
  state trajectory (e.g. "vehicle is tipping at 200 °/s") without flying.
- **`ILink`** — lets the vehicle be driven from USB serial during bring-up
  before ESP-NOW works, and keeps a BLE implementation available as a drop-in
  if a phone/tablet control path is ever wanted. See
  [communication.md](communication.md).

Everything else is a concrete class. Do not add an interface without a second
implementation that actually exists.

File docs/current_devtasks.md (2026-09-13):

# Build order

The ordering rule: **nothing depends on something unproven.** Each phase ends
with a concrete, observable check. If that check does not pass, do not start
the next phase — every one of these bugs is cheaper to fix now than after it is
buried under three more layers.

Propellers stay **off** until Phase 11 says otherwise.

Legend: `[ ]` todo · `[~]` in progress · `[x]` done

---

## Phase 0 — Repository scaffolding

- [ ] `[0.1]` Create `controller/` as a second PlatformIO project (`esp32dev`,
      Arduino, C++17 — mirror `firmware/platformio.ini`).
- [ ] `[0.2]` Create `shared/link/protocol.h` with the packet definitions from
      [communication.md](communication.md). Add `-I ../shared` to the
      `build_flags` of **both** projects so the framing is defined exactly once.
- [ ] `[0.3]` Add a `native` environment to `firmware/platformio.ini` for
      host-side unit tests, with a source filter that excludes hardware code.
- [ ] `[0.4]` Add Unity test scaffolding under `firmware/test/`. Get one
      trivial passing test running under `pio test -e native` before writing
      real ones.
- [ ] `[0.5]` Confirm `firmware/.pio/` is gitignored and no build artifacts are
      tracked.

**Check:** `pio run -e esp32dev` and `pio test -e native` both pass in
`firmware/`; `controller/` builds an empty sketch.

---

## Phase 1 — HAL and board bring-up

- [ ] `[1.1]` Write the pin map into `firmware/include/board/pins.h` as the
      single source of truth. Cross-check every pin against the strapping and
      input-only constraints in [hardware.md](hardware.md).
- [ ] `[1.2]` HAL wrappers: GPIO, SPI, I2C, LEDC/RMT, ADC1, `micros()`.
      Thin — no flight logic.
- [ ] `[1.3]` Serial console with a non-blocking print path. Nothing in the
      1 kHz loop may ever call it directly.
- [ ] `[1.4]` I2C bus scanner utility. You will use this constantly in Phase 2.

**Check:** blink an LED, print at 115200, scan the I2C bus and see devices.

---

## Phase 2 — Drivers

### 2a — IMU

- [ ] `[2.1]` `Icm20948Spi implements IImuSource`. Cut the SparkFun board's
      I2C/SPI jumper and wire SPI — see the rate argument in
      [hardware.md](hardware.md).
- [ ] `[2.2]` WHO_AM_I check, ranges (±2000 °/s gyro, ±8 g accel), DLPF config.
- [ ] `[2.3]` Data-ready interrupt → flag → read in the loop. Do **not** read
      inside the ISR.
- [ ] `[2.4]` Convert to SI units in the driver. Nothing downstream sees LSBs.
- [ ] `[2.5]` AK09916 magnetometer at ~100 Hz with its own valid flag.
- [ ] `[2.6]` Axis alignment: confirm +X forward, +Y right, +Z down. Rotate in
      the driver if the physical mounting differs. **Write down the convention
      and check it physically** — a swapped axis produces a control loop that
      is wrong in a way that looks like bad tuning.

**Check:** 1 kHz stream; gravity reads ≈9.81 on the down axis in all six
orientations; gyro reads ≈0 at rest and the correct sign when rotated.

### 2b — ToF pair

- [ ] `[2.7]` Wire both `XSHUT` pins to their own GPIOs.
- [ ] `[2.8]` Implement the boot address-assignment sequence from
      [hardware.md](hardware.md): both low → release A → set A to `0x30` →
      release B. **Verify with a bus scan** that exactly two devices answer at
      the expected addresses.
- [ ] `[2.9]` `Vl53l0xRanger` producing `RangeData`. Continuous mode,
      asynchronous — start ranging, poll for ready, never block.
- [ ] `[2.10]` Map range status codes to `valid`. Out-of-range must report
      invalid, not a large distance.
- [ ] `[2.11]` Measure and record: the baseline between sensors, each sensor's
      offset from the CG, and leg length at full extension. Into `Parameters`.

**Check:** both sensors report independently and correctly at a known height;
covering one does not disturb the other.

### 2c — Motors and battery

- [ ] `[2.12]` ESC driver: disarmed value at boot, arming sequence, normalized
      `0.0–1.0` input.
- [ ] `[2.13]` Motor test mode — spin one motor at a time from a serial
      command. **Props off.** Confirm the numbering and rotation direction of
      each motor against the mixer diagram in
      [control_loop.md](control_loop.md).
- [ ] `[2.14]` **Verify thrust direction physically** with props fitted, frame
      held down, one motor at a time: confirm each produces **upward** thrust.
      The props mount below the arms (pusher config), so either the prop
      handedness or the motor direction must be flipped relative to a
      top-mounted quad — one or the other, never both. Getting this wrong
      produces a vehicle that drives itself into the ground at full authority.
      Record the convention in [hardware.md](hardware.md).
- [ ] `[2.15]` Measure `leg_length`, `prop_bottom_offset`, and
      `prop_radius_from_CG`; compute the prop-strike tilt limit from the
      inequality in [hop_mode.md](hop_mode.md) and store all four in
      `Parameters`. This number sets `hop_max_tilt` later — it is not a
      comfort setting.
- [ ] `[2.16]` With motors spinning, confirm the ToF pair still reads cleanly.
      Props mounted low sit near the sensors' ~25° cone; blade intrusion shows
      up as spurious short readings at blade-pass frequency, which the
      estimator would read as a false ground contact.
- [ ] `[2.17]` Battery sense divider (see [hardware.md](hardware.md)) on ADC1;
      calibrate the reading against a meter.
- [ ] `[2.18]` Low-pass filter for battery voltage, plus the raw value for
      logging. Read the sag argument in [safety.md](safety.md) before
      choosing a threshold.

**Check:** each motor spins on command with correct numbering and direction;
thrust confirmed **upward** on all four; ToF clean with props spinning;
battery voltage matches a meter within 0.1 V.

---

## Phase 3 — Scheduler

- [ ] `[3.1]` 1 kHz fixed-rate task pinned to **core 1**.
- [ ] `[3.2]` Sub-rate dispatch by tick modulo, with staggered phases (see
      [scheduler.md](scheduler.md)).
- [ ] `[3.3]` Loop timing instrumentation: execution time and inter-tick
      jitter, min/mean/max.
- [ ] `[3.4]` Overrun detection feeding the watchdog failsafe.
- [ ] `[3.5]` Lock-free SPSC buffer for core 1 → core 0 handoff.

**Check:** with all Phase 2 drivers running, hot-path time stays under 400 µs
and jitter under 50 µs. Fix it here if not — everything downstream inherits it.

---

## Phase 4 — Estimator

- [ ] `[4.1]` Gyro bias calibration at rest during `INITIALIZING`, with a
      motion-detect reject.
- [ ] `[4.2]` Mahony attitude filter. Test on the host against synthetic
      samples first.
- [ ] `[4.3]` **Accelerometer trust gate** — reject the accel correction when
      `| ||a|| − 9.81 |` exceeds the band. This is what stops the attitude
      estimate tumbling during launch bursts and touchdown impacts. Non-optional
      for a hopcopter; see [estimator.md](estimator.md).
- [ ] `[4.4]` Magnetometer yaw trim at low gain, with magnitude rejection.
      Never let it touch roll or pitch.
- [ ] `[4.5]` Tilt-compensate each ToF range; invalidate beyond
      `tof_max_tilt`.
- [ ] `[4.6]` Cross-check the two heights; produce `height_confidence` and
      `ground_slope_rad`.
- [ ] `[4.7]` Height/vertical-velocity/accel-bias complementary filter:
      predict at 1 kHz, correct at 50 Hz.
- [ ] `[4.8]` Ground-contact detection: range **and** accel spike, latched with
      hysteresis.
- [ ] `[4.9]` Freshness timeouts and `healthy()` per the table in
      [estimator.md](estimator.md).

**Check:** tilt the frame by hand — roll/pitch track accurately in every
orientation and return cleanly to level with no drift. Shake it hard: attitude
must **not** tumble. Lift and lower it: height tracks; contact latches on the
bench and clears when lifted.

**Do not proceed until attitude is solid.** Everything after this is built on
it.

---

## Phase 5 — Link (serial first)

- [ ] `[5.1]` `ILink` interface: `open`, `send`, `poll`, `connected`,
      `last_rx_us`.
- [ ] `[5.2]` Frame encoder/decoder in `shared/link/`. Host-testable.
- [ ] `[5.3]` **Host unit tests for the parser**: truncated frames, bad CRC,
      reordered and replayed sequence numbers, garbage bytes mid-frame,
      resynchronization after corruption. Cheap tests, expensive bugs.
- [ ] `[5.4]` `SerialLink` over USB. Bring the whole stack up on this before
      touching ESP-NOW.
- [ ] `[5.5]` `TLM_STATE` telemetry at 10 Hz, queued to core 0.
- [ ] `[5.6]` Parameter get/set over the link, backed by NVS, with defaults,
      min/max, and range rejection.

**Check:** a host script reads live telemetry and changes a parameter that
persists across reboot.

---

## Phase 6 — Controller firmware (the transmitter)

Both controller forms produce the **same** `CMD_CONTROL` intent packet
(`roll_cmd`/`pitch_cmd`/`yaw_rate_cmd`/`climb_rate_cmd` + `request`), so the
vehicle can't tell them apart. Build 6a first — it is the replicable reference
and the simpler radio path. 6b is the DS4/SCUF gamepad option.

### 6a — Reference joystick controller

- [ ] `[6.1]` Joystick ADC on **ADC1 only** (GPIO 36/39).
- [ ] `[6.2]` Calibration routine: record centre and both endpoints per axis,
      persist to NVS. Do not assume 2048 is centre.
- [ ] `[6.3]` Deadband around centre, normalize to −1000..1000, apply an
      expo curve for fine control near centre.
- [ ] `[6.4]` `SEL` button with `INPUT_PULLUP` and ~20 ms debounce.
- [ ] `[6.5]` Gesture recognizer: short click, long press 1.5 s, double click,
      3 s hold — per the joystick gesture table in
      [flight_modes.md](flight_modes.md). The double-click hop toggle resolves
      to `SET_HOP` / `SET_HOVER` using the vehicle state from `TLM_STATE` — the
      wire never carries a toggle.
- [ ] `[6.6]` Control-scheme cycling `TILT → HEADING → ALTITUDE` with local LED
      indication, and **intent resolution**: fill the four `CMD_CONTROL` fields
      from the two axes + current scheme, holding the non-driven tilt field and
      resting rate fields at zero.
- [ ] `[6.7]` Emit `CMD_CONTROL` at 50 Hz **unconditionally**. The stream is
      the heartbeat; a gap in it is the failsafe signal.
- [ ] `[6.8]` Hold each `request` value ~100 ms so one dropped packet does not
      lose a button press.
- [ ] `[6.9]` Consume telemetry: LED and buzzer patterns for disarmed / armed /
      flying / hopping / failsafe / link-lost.

**Check:** on serial, every axis + scheme produces the correct resolved intent,
and every gesture the correct `request`. Verify the 3-second emergency-stop
hold before anything can spin.

### 6b — Gamepad + ground dongle (optional, DS4/SCUF)

- [ ] `[6.10]` Dongle ESP32 pairs the DS4 over Bluetooth Classic
      (Bluepad32). Bind one controller; do not auto-accept others.
- [ ] `[6.11]` Map inputs per the DS4 table in
      [flight_modes.md](flight_modes.md): two sticks → the four intent fields
      (no scheme cycling); ✕ → `LAND`, ○ → `SET_HOP`, △ → `SET_HOVER`;
      L1+R1 hold 1.5 s → `ARM`/`DISARM`; touchpad hold ~2 s → `ESTOP`.
- [ ] `[6.12]` **Dongle generates `CMD_CONTROL`** and sends it over ESP-NOW —
      the laptop is never in the flight path. Same 50 Hz unconditional stream
      and ~100 ms request-hold as 6a.
- [ ] `[6.13]` Controller-side extras that never touch the vehicle: L2-hold
      precision mode (scale all four intent fields to ~40%), D-pad ←/→ trim
      offsets, Share → log marker. These shape or annotate intent before it is
      sent.
- [ ] `[6.14]` D-pad ↑/↓ adjusts `hop_height_target` via `CMD_PARAM_SET` — add
      that parameter to the refuse-while-armed in-flight allowlist.
- [ ] `[6.16]` Button/axis mapping stored as parameters, editable from the
      laptop via `CMD_PARAM_SET` — remap without reflashing the dongle.
- [ ] `[6.17]` Dongle forwards `TLM_STATE` **and** its own decoded DS4 state up
      USB to the ground station (Phase 7 consumes both).
- [ ] `[6.18]` **Measure BT-Classic + ESP-NOW coexistence** on the dongle:
      confirm the 50 Hz command stream holds its rate and latency with the DS4
      link active. This is the one real risk in the gamepad path.

**Check:** with the dongle only (laptop closed), the DS4 arms, flies, and
emergency-stops the vehicle exactly as the joystick does — proving the vehicle
is genuinely controller-agnostic.

---

## Phase 7 — Ground station

Built here, before the control loop closes, because it is a **debugging
instrument** — it pays for itself across Phases 8–12. See
[ground_station.md](ground_station.md).

- [ ] `[7.1]` Controller forwards a combined record up the USB cable it is
      already plugged into for power: the vehicle's `TLM_STATE` plus its own
      raw input and the resolved intent it is sending (joystick: stick +
      control scheme; dongle: both DS4 sticks + button states).
- [ ] `[7.2]` Host bridge process: read USB serial, decode using the
      definitions in `shared/link/`, re-serve over WebSocket. Python or Node —
      pick the one you'll actually maintain.
- [ ] `[7.3]` Bridge writes to disk **whether or not a browser is connected**.
      **One timestamped log file per arm/disarm cycle** — open on the
      `vehicle_state` transition into `ARMED`, close on the transition back to
      `DISARMED`. This is the black box for anything that goes wrong, and the
      per-flight boundary is what makes the blackbox tooling in Phase 13 able
      to reach for "the last flight" without slicing a continuous log.
- [ ] `[7.4]` Dashboard: vehicle state, per-failsafe tripped indicators,
      battery with thresholds marked, estimator health, `height_confidence`.
- [ ] `[7.5]` Dashboard: **which arming precondition is currently failing.**
      [safety.md](safety.md) already requires the vehicle to report this;
      this is where it becomes impossible to miss.
- [ ] `[7.6]` Rolling time-series plots — roll, pitch, yaw, height, vertical
      velocity. These matter more than a 3D view: oscillation and overshoot
      are obvious in a trace and invisible in an orientation cube.
- [ ] `[7.7]` Controller panel: the four resolved intent fields, plus the raw
      input beneath them — joystick stick as a 2D dot with deadband drawn
      (**post-calibration, post-expo**) and control scheme, or the dongle's two
      DS4 sticks and button states. Seeing intent diverge from raw input is how
      a miscalibrated centre or a backwards mapping becomes visible.
- [ ] `[7.8]` Link quality: packets/sec, `rx_loss_pct`, CRC errors, sequence
      gaps, and time-since-last-command drawn against the 150 ms / 300 ms / 1 s
      failsafe ladder.
- [ ] `[7.9]` **Read-only for anything flight-critical.** Arming, mode changes,
      and emergency stop stay on the physical controller. Parameter tuning is
      the one exception, through the existing `CMD_PARAM_SET` rules.

**Check:** with the vehicle on the bench, tilt it by hand and watch attitude
track live in the browser; move the stick and watch the dot move; pull the
link and watch the failsafe ladder count up.

---

## Phase 8 — Modes, control, mixing

- [ ] `[8.1]` Vehicle state machine from [flight_modes.md](flight_modes.md),
      with all illegal transitions rejected. Host-tested.
- [ ] `[8.2]` Intent → `DesiredState`: scale the normalized `CMD_CONTROL`
      fields against `max_tilt` / `max_yaw_rate` / `max_climb_rate` and
      **clamp** to the safety envelope. No axis-mode logic here — the vehicle
      receives resolved intent, not raw axes (see
      [communication.md](communication.md)).
- [ ] `[8.3]` Arming gesture with the **full precondition list** from
      [safety.md](safety.md), reporting which check failed.
- [ ] `[8.4]` Rate PID: D on measurement, low-pass filtered, clamped
      integrators.
- [ ] `[8.5]` Angle P loop feeding rate setpoints. **P only** — no I term here.
- [ ] `[8.6]` Yaw rate PI.
- [ ] `[8.7]` Altitude PID producing collective thrust; climb-rate command
      integrating into a held height.
- [ ] `[8.8]` Quad-X mixer with prioritized saturation handling
      (roll/pitch > thrust > yaw) and a `saturated` flag. **Verify the yaw
      signs independently** — the pusher prop mounting likely inverts them
      relative to the diagram in [control_loop.md](control_loop.md).
- [ ] `[8.9]` Anti-windup: freeze integrators whenever the mixer saturates.
- [ ] `[8.10]` **Freeze/bleed rate integrators while ground contact is
      latched**, reset at launch — otherwise every takeoff kicks.
- [ ] `[8.11]` Host unit tests: mixer allocation and saturation, PID step
      response, every state transition.

**Check (bench, props off, frame clamped):** tilt the frame by hand and confirm
the correct motors spool up to oppose the motion, on all three axes
independently. Watch it on the ground station. A sign error is obvious here and
unflyable later.

---

## Phase 9 — Safety

- [ ] `[9.1]` Safety module positioned **after** the mixer and before the motor
      write, holding the only path to the ESCs.
- [ ] `[9.2]` Failsafes 1–12 from [safety.md](safety.md).
- [ ] `[9.3]` Latching policy: estop and watchdog latch until power cycle;
      link-loss and battery clear as conditions but their landing completes.
- [ ] `[9.4]` Link-loss ladder: 150 ms warn → 300 ms failsafe → 1 s descend →
      disarm on touchdown.
- [ ] `[9.5]` Battery thresholds against the **filtered** voltage with a
      sustained-duration requirement, so launch bursts do not trip it.
- [ ] `[9.6]` Ring-buffer black box: every failsafe trip with timestamp and the
      state that caused it. Flush after landing, never in the hot path.
- [ ] `[9.7]` Emergency stop verified reachable from **every** state.

**Check:** deliberately trigger each failsafe on the bench — unplug the ToF
sensors, walk the controller out of range, hold the frame past 50°, drop the
supply voltage — and confirm the documented response every time, watching the
ground station's failsafe indicators.

---

## Phase 10 — ESP-NOW

- [ ] `[10.1]` `EspNowLink implements ILink`. No server/client asymmetry to
      design — both sides register the other as a peer and send.
- [ ] `[10.2]` `COMMAND` and `TELEMETRY` as fixed-size `esp_now_send()` frames;
      never block on the delivery callback before sending the next packet.
- [ ] `[10.3]` Peer binding: each side stores the other's MAC in NVS, registers
      only that MAC as a peer at boot, and rejects frames from any other
      source MAC. Explicit pairing gesture required to learn a new MAC.
- [ ] `[10.4]` Measure real round-trip latency and packet loss over range.
      `BleLink` is the documented fallback and `ILink` makes it a swap, not a
      rewrite, if ever needed.
- [ ] `[10.5]` Optional: per-peer AES-CTR encryption once the unencrypted link
      is proven.
- [ ] `[10.6]` Re-run the **entire** Phase 9 failsafe check over ESP-NOW. The
      link changed; the failsafes must be re-verified against it.

**Check:** full control over ESP-NOW with the vehicle tethered, props off.
Link loss at range produces the correct failsafe ladder.

---

## Phase 11 — First flight

Initial gain tuning happens on the rig, **not** in free flight. Free flight is
where you validate and fine-tune those rig-derived gains against real
aerodynamics — it is not where you discover them for the first time.

### 11a — Rig tuning

Props on, mounted on the PID tuning rack. The rig constrains translation but
allows free rotation about a fixed point, so the vehicle can actually execute
its PID corrections and you can watch real closed-loop response — overshoot,
oscillation, damping — with zero risk of a flyaway or a crash if a gain is
wrong. This is the right place to find out a gain is unstable, not hovering
freehand.

- [ ] `[11.1]` Mount on the rig. Confirm free rotation on all three axes with
      translation fully constrained before spinning a motor.
- [ ] `[11.2]` Tune the rate loop — P until oscillation, back off ~30%, then
      D, then I. One gain at a time, log everything via the ground station.
- [ ] `[11.3]` Tune the angle P loop: command a step tilt and confirm it
      reaches and holds the target angle without overshoot ringing into the
      rate loop.
- [ ] `[11.4]` Tune the yaw PI loop (`HEADING` mode) the same way.
- [ ] `[11.5]` Disturbance test: perturb the frame by hand on the rig, on each
      axis independently, and confirm it recovers to commanded attitude
      cleanly — this is your cheapest look at real damping before it matters
      in the air.

**Check:** on the rig, the vehicle holds a commanded tilt on all three axes,
recovers cleanly from a hand disturbance, and shows no D-term noise or
oscillation at the tuned gains.

**What the rig cannot tune:** it constrains translation, so it cannot
validate altitude hold, ground-effect response, or anything that depends on
the vehicle actually moving through air it disturbs itself. Those still need
free flight — the rig gets the rotational loops close, not complete.

### 11b — Free hover

Outdoors or a large open space, tether where practical, emergency stop under
your thumb, a spotter, and the ground station recording. Only after 11a's
check passes.

- [ ] `[11.6]` First free hover using the rig-tuned gains as the starting
      point. Expect only minor retuning — real prop wash, ground effect, and
      airframe asymmetry aren't present on the rig.
- [ ] `[11.7]` Hover trim: adjust until it holds level with a centred stick.
- [ ] `[11.8]` Fine-tune rate/angle gains in free air if the rig-derived
      values aren't quite right. One gain at a time, same discipline as 11a.
- [ ] `[11.9]` Tune altitude hold; verify climb-rate command and height hold.
      This loop gets its **first** real tuning here — the rig can't exercise
      it.
- [ ] `[11.10]` Verify `HEADING` mode yaw rate in free flight.
- [ ] `[11.11]` Verify each failsafe **in flight**, one at a time, at low
      altitude over something soft.

**Check:** stable hover, responsive tilt, altitude holds within ~10 cm, every
failsafe behaves as documented.

---

## Phase 12 — Hop mode

Only after Phase 11 is fully complete. Read [hop_mode.md](hop_mode.md) first —
the bring-up sequence there is the detailed version of this list.

- [ ] `[12.1]` Hop phase machine at 1 kHz, producing `HopState`.
- [ ] `[12.2]` Bottom-of-stroke detection: vertical velocity crossing zero
      while contact is latched.
- [ ] `[12.3]` Launch burst: `hop_burst_thrust` for `hop_burst_ms`, fired at
      extension.
- [ ] `[12.4]` Ballistic phase at `hop_idle_thrust` with **attitude control
      fully active**. Verify the mixer still has torque authority at idle
      collective — this is the failure mode that tumbles the vehicle.
- [ ] `[12.5]` Apex detection and peak-height capture, tolerating ToF dropout
      above ~1.2 m by coasting on the inertial filter.
- [ ] `[12.6]` Descent: tilt steering, pre-tilt to `ground_slope_rad`.
- [ ] `[12.7]` Closed-loop hop-height regulation — proportional, clamped,
      updated **once per hop**.
- [ ] `[12.8]` Every abort condition from [hop_mode.md](hop_mode.md).
- [ ] `[12.9]` `SET_HOP` / `SET_HOVER` requests wired end to end from both
      controllers (joystick double-click resolving to the correct explicit
      request; DS4 ○ / △ buttons).
- [ ] `[12.10]` Hop phase timeline on the ground station, aligned against the
      height and vertical-velocity traces. This is the single most useful view
      for hop tuning — it is how you see whether the burst is firing at
      extension or missing the window.
- [ ] `[12.11]` High-rate hop logging to the ring buffer; flush after landing.
- [ ] `[12.12]` Tethered bring-up, steps 1–5 of
      [hop_mode.md](hop_mode.md#bring-up-order). Start the burst at 25 % and
      expect it not to leave the ground.

**Check:** repeatable hops at a commanded height, upright attitude through the
entire airborne phase, tilt steering the landing point, and every abort
condition verified.

---

## Phase 13 — Tooling and polish

- [ ] `[13.1]` Offline log decoder and hop-cycle analyzer over the bridge's
      session logs.
- [ ] `[13.2]` PID tuning helper — parameter sweeps driven from the ground
      station.
- [ ] `[13.3]` Endurance test: hopping vs hovering runtime on the same pack.
      This is the number the whole design exists to improve.
- [ ] `[13.4]` Record final tuned parameters and wiring in the docs.

---

## Phase H — Hardware iteration (parallel track)

Runs alongside the phases above and **must never block them**. Rationale,
part selection and the reasoning behind each step are in
[hardware_roadmap.md](hardware_roadmap.md).

### H1 — 4-in-1 ESC swap

- [x] `[H.1]` Buy a 30.5 × 30.5, **3–6 S**, 45–60 A 4-in-1. Chosen: **Skystars
      KO50A**. 5 V regulator: **Pololu D24V10F5**. Both ordered.
- [x] `[H.2]` Record its ribbon pinout before designing anything against it.
      Confirmed: `GND · BAT · S1 · S2 · S3 · S4 · NC · CURR`. No BEC, so the
      5 V rail is ours. See [hardware_roadmap.md](hardware_roadmap.md).
- [ ] `[H.3]` Replace the four discrete ESCs. Re-verify motor ordering against
      the pin map in [hardware.md](hardware.md) and re-run the thrust-direction
      check `[2.14]` — the mapping is easy to get wrong during this swap.
- [ ] `[H.4]` Confirm the ESCs still see a valid idle signal before arming.
- [ ] `[H.4a]` Fit an anti-spark XT60 to the ESC's battery pads along with the
      supplied bulk capacitor. **No switch in the motor path** — the connector
      is the disconnect, see the roadmap.

**Check:** all four motors respond to the correct commanded channel, same
behaviour as before the swap, no brownouts under throttle transients.

### H2 — Carrier board (first PCB)

- [x] `[H.5]` KiCad work lives in [eli-lame/Genli](https://github.com/eli-lame/Genli),
      one project per board, with every library vendored. The Stage 2 spec is
      `stage2-carrier/README.md` there.
- [ ] `[H.6]` Schematic: devkit socket, 8-pin ESC ribbon, IMU and ToF
      connectors, D24V10F5 footprint with a 33 µF+ electrolytic at its input,
      TVS at the BAT entry, **battery divider** (absent from the v1 schematic —
      see the roadmap), `CURR` to an ADC1 pin, status LED, buzzer.
- [ ] `[H.6a]` If an FC power switch is fitted, place it downstream of the BAT
      entry and upstream of both the buck and the divider, and label it
      `FC POWER — NOT A SAFETY DISCONNECT` in the schematic.
- [ ] `[H.7]` Add a 4-pin JST-SH footprint on a spare UART (5 V, GND, TX, RX),
      wired and unpopulated, so ELRS is later a firmware change rather than a
      respin.
- [ ] `[H.8]` 2-layer layout, 30.5 × 30.5 mounting, ERC and DRC clean.
- [ ] `[H.9]` Fabricate, assemble by hand, bring up on a current-limited supply
      with rails verified before the MCU is powered.
- [ ] `[H.10]` Calibrate the battery divider against a meter — this is `[2.17]`,
      finally possible.

**Check:** the vehicle flies on the carrier board with the same firmware binary
it ran on the breadboard.

### H3 — Integrated FC

- [ ] `[H.11]` 4-layer board: bare MCU module, ICM-42688-P, integrated buck,
      USB. Drop-in replacement for H2 — same pin functions, same connector
      positions.
- [ ] `[H.12]` Select every part against the fab's assembly library before
      finalising the schematic.
- [ ] `[H.13]` Soft-mount, conformal coat, bring up as in `[H.9]`.

**Check:** as H2. If this board does not work, the vehicle still flies on H2
hardware and nothing downstream is blocked.

---

## Standing rules

1. **Props off** until Phase 11 — the only exceptions before then are the
   thrust-direction check in `[2.14]` and the ToF-with-props check in
   `[2.16]`, both with the frame held down. Phase 11 itself starts on the PID
   tuning rack (`11a`, constrained rotation, no flyaway risk) before free
   hover (`11b`) is attempted.
2. **Never skip a phase check.** They are ordered so each failure is cheap and
   isolated.
3. **Attitude control never stops** — not in any hop phase, not ever.
4. **Log before you need it.** You get one flight's worth of evidence and no
   ability to reproduce a crash.
5. **One variable at a time** when tuning.
6. **Host-test everything that will compile on a host.** Mixer, PID, state
   machines, and the link parser are the cheapest bugs you will ever fix.

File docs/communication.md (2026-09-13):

# Communication

## Link

**ESP-NOW** between the controller ESP32 and the vehicle ESP32. ESP-NOW is
Espressif's connectionless protocol built on the raw WiFi radio — no pairing,
no connection handshake, no association state. Each side just addresses a
packet to the other's MAC and sends it. That fits a real-time control link
better than a connection-oriented protocol: typical latency is ~1–4 ms
(vs. BLE's ~7.5 ms connection-interval floor, often more in practice), and if
a packet is lost there's no connection to re-establish — the next one just
goes out.

ESP-NOW is the link for the current hardware generation and is not a
placeholder to be rushed past. The eventual target is an ExpressLRS receiver
over CRSF for control with telemetry on a separate path — see
[hardware_roadmap.md](hardware_roadmap.md) — but that migration is deliberately
held until the board and power architecture have stopped changing. Because the
wire packet carries *intent* rather than raw throttle, CRSF slots in behind the
same interface when the time comes, and nothing above the link layer changes.

Here "the controller ESP32" means whichever peer you built — the reference
joystick controller *or* the DS4/SCUF ground dongle. Both are ESP32s that speak
ESP-NOW to the vehicle, and the vehicle cannot tell them apart (see
[architecture.md](architecture.md)). A DS4 gamepad connects to the *dongle*
over Bluetooth Classic; it never touches this ESP-NOW link.

The vehicle registers the controller's MAC (and vice versa) as a peer at boot,
from a value stored in NVS — see **Pairing** below. Both sides send fixed-size
frames with `esp_now_send()`; there is no server/client asymmetry to design
around, unlike GATT.

| Stream | Direction | Rate |
|---|---|---|
| `COMMAND` | controller → vehicle | 50 Hz |
| `TELEMETRY` | vehicle → controller | 10 Hz |

Send and move on — do not wait on `esp_now_send()`'s delivery callback before
sending the next packet. For a stream where the next sample supersedes the
last, blocking on a per-packet delivery confirmation is pure added latency
with no benefit. Loss is handled by sequence numbers and the link-loss
timeout, not by waiting for acknowledgment.

### ILink: ESP-NOW is the target, everything else is a seam

**ESP-NOW is the transport being built.** It's the only one scheduled in
[current_devtasks.md](current_devtasks.md) (Phase 9) and the only one that
ships on the finished vehicle.

Two things sit behind the same `ILink` interface (`open`, `send`, `poll`,
`connected`, `last_rx_us`) purely so nothing above the transport has to be
rewritten if the transport changes:

- **`SerialLink`** — USB serial, built *first* (Phase 5), before ESP-NOW
  exists. Lets the mode manager, controller, and safety logic be brought up
  and tested on the bench over a cable, so the control loop and the radio
  stack aren't being debugged at the same time.
- **`BleLink`** — **not implemented, not scheduled.** A documented fallback
  only, kept in reserve for the one thing ESP-NOW can't do: let a generic phone
  or tablet *be the controller*, with no dedicated hardware on the ground at
  all. (This is unrelated to the DS4 gamepad option — that gamepad reaches the
  vehicle through the dongle's ESP-NOW link, not over BLE. See
  [architecture.md](architecture.md).) Nothing in the plan needs a phone-as-
  controller path, so this isn't being built; it's noted only so that if it is
  ever wanted, it's a new `ILink` implementation rather than a redesign of
  everything above the transport.

## The gamepad link (DS4 → dongle)

Applies only to the gamepad controller (form B in
[architecture.md](architecture.md)). The reference joystick has no such link —
it reads its stick straight off an ADC.

**Transport: Bluetooth Classic HID, handled by [Bluepad32](https://bluepad32.readthedocs.io/)
on the dongle.** The dongle is the Bluetooth host; the DS4/SCUF is a standard
HID gamepad peripheral. We do **not** design this protocol — the controller
defines its HID reports and Bluepad32 decodes them into stick and button state.
None of the `MAGIC`/`SEQ`/`CRC16` framing below applies to it; that framing is
for *our* protocol (the dongle↔vehicle ESP-NOW link and the serial bring-up
link).

**What it carries: raw gamepad state** — two analog sticks, triggers, buttons.
*Not* intent. The dongle reads this state and **generates** `CMD_CONTROL` from
it, applying the mapping in [flight_modes.md](flight_modes.md). Interpretation
lives on the dongle; this link sits upstream of it. The DS4 never emits an
intent packet and never touches ESP-NOW.

Characteristics to design around:

- **Range ~10 m.** Bluetooth Classic is couch-to-console range. Because the
  dongle sits by the laptop, *you* must stay within ~10 m of the ground
  station. Fine for a hopcopter working near you; a real constraint to know
  going in. (The vehicle's ESP-NOW range is far longer — the gamepad hop is now
  the limiting leg.)
- **Latency ~4–11 ms** per HID report, on top of the ESP-NOW leg. Acceptable
  for tilt commands, but it stacks — measure end-to-end as part of the
  coexistence check.
- **Radio coexistence.** The dongle runs Bluetooth Classic *and* ESP-NOW on one
  chip. This is the single real risk in the gamepad path: verify the 50 Hz
  command stream holds its rate and latency with the DS4 link active
  (`[6.18]` in [current_devtasks.md](current_devtasks.md)).

**Binding:** pair exactly one DS4, stored on the dongle, and do not auto-accept
the first gamepad that advertises — same philosophy as the ESP-NOW **Pairing**
section below. An unbound controller must not be able to fly the vehicle.

## Framing

Same frame on every transport, so the parser is written and tested once.

```
┌────────┬──────┬─────┬────────┬─────────┬───────┐
│ MAGIC  │ TYPE │ SEQ │ LENGTH │ PAYLOAD │ CRC16 │
│ 2 B    │ 1 B  │ 1 B │  1 B   │  0-64 B │  2 B  │
└────────┴──────┴─────┴────────┴─────────┴───────┘
```

- `MAGIC` — `0xC4 0x0A`. Resynchronization point for the byte-stream
  transports; cheap sanity check on the packet ones.
- `SEQ` — increments per packet, wraps at 256. Detects loss and, critically,
  **detects reordering and duplication**. Drop any command whose sequence is
  older than the last accepted one.
- `CRC16` — CCITT, over `TYPE` through `PAYLOAD`. ESP-NOW's WiFi framing has
  its own CRC and the serial transport does not; validating at this layer
  regardless means one parser is trusted everywhere instead of relying on a
  transport-level guarantee that not every transport provides.

Reject silently and count the failure. Never act on a packet that fails any
check, and never let a malformed packet stall the parser — a receiver that can
be wedged by one bad byte is a receiver that fails permanently on the first
glitch.

## Packet types

### `CMD_CONTROL` — controller → vehicle, 50 Hz

The only packet that flies the vehicle. It carries **intent**, not raw stick
positions: each field has one fixed meaning, already resolved by the
controller. The vehicle never learns what kind of device produced it — a
one-stick joystick doing mode-cycling and a two-stick gamepad commanding
everything at once emit the identical packet.

| Field | Type | Meaning |
|---|---|---|
| `roll_cmd` | int16 | desired roll, −1000..1000 = −max..+max tilt |
| `pitch_cmd` | int16 | desired pitch, −1000..1000 = −max..+max tilt |
| `yaw_rate_cmd` | int16 | desired yaw **rate**, −1000..1000 = −max..+max |
| `climb_rate_cmd` | int16 | desired climb **rate**, −1000..1000; **0 = hold height** |
| `request` | uint8 | `NONE` / `ARM` / `DISARM` / `LAND` / `SET_HOP` / `SET_HOVER` / `ESTOP` |
| `flags` | uint8 | bit 0: controller has a known-neutral input this tick |

The four command fields are **normalized fractions of the vehicle's configured
maxima**, not physical angles or rates. The controller says "70% of max roll,
zero yaw rate, 20% climb"; the vehicle scales each against its own
`max_tilt` / `max_yaw_rate` / `max_climb_rate` parameters and **clamps**. This
is deliberate: every physical limit — and therefore every safety envelope —
stays on the vehicle, exactly where [safety.md](safety.md) already puts the
attitude and height limits. A miscalibrated or misbehaving controller cannot
command past them.

`climb_rate_cmd = 0` means *hold current height*, not *cut thrust*. The
vehicle integrates the commanded rate against its own height estimate into a
held target (see `DesiredState` in [data_model.md](data_model.md)). The
joystick never has direct authority over collective thrust — that property is
preserved verbatim from the original design.

Sent **continuously at 50 Hz whether or not anything changed**. The stream is
the heartbeat; there is no separate keepalive. A gap in the stream *is* the
failsafe signal, and that only works if the stream is unconditional.

`request` is edge-triggered on the vehicle. The controller holds a request
value for ~100 ms (5 packets) so a single dropped packet does not lose a button
press, and the vehicle acts on the transition, not the level.

`SET_HOP` and `SET_HOVER` are **explicit, idempotent** states, deliberately not
a single toggle. Asking for a state the vehicle is already in is a harmless
no-op; there is no way for a mis-fire to flip you the wrong way. A two-stick
gamepad puts these on separate buttons; the one-stick joystick offers a single
toggle *gesture* that its firmware resolves — using the vehicle state it reads
from `TLM_STATE` — into whichever of the two explicit requests is correct. Both
send the same two request values.

Adjusting the hop **height target** is not a request — it goes through
`CMD_PARAM_SET` on `hop_height_target`, which must therefore be on the
refuse-while-armed in-flight allowlist. Requests are for discrete state
transitions; continuously-tunable values are parameters.

**Why intent and not raw axes.** The interpretation of "what the pilot wants"
is a property of the *input device*, not the aircraft — it depends on how many
sticks and buttons that device has. Putting it on the wire as intent keeps
that device-specific logic on the controller and leaves the vehicle's
command-handling uniform and device-agnostic. Adding a new controller type
never touches flight-critical firmware. See
[flight_modes.md](flight_modes.md) for how each device fills these four
fields.

### `TLM_STATE` — vehicle → controller, 10 Hz

| Field | Type |
|---|---|
| `timestamp_ms` | uint32 |
| `vehicle_state` | uint8 |
| `roll_deg`, `pitch_deg`, `yaw_deg` | int16 ×3 |
| `height_cm` | int16 |
| `battery_mv` | uint16 |
| `hop_phase` | uint8 |
| `status_flags` | uint16 |
| `rx_loss_pct` | uint8 |

There is no `axis_mode` field here anymore — the vehicle has no notion of axis
modes. If a controller has an internal control-scheme mode (the one-stick
joystick does; a gamepad does not), that is the controller's own state, known
to it locally, and never round-tripped through the vehicle.

`status_flags` carries armed, each failsafe's tripped bit, estimator health,
and ToF confidence. The controller uses these to drive its LED and buzzer — the
pilot must be able to tell armed from disarmed, and healthy from degraded,
without looking at a laptop.

### `CMD_PARAM_SET` / `CMD_PARAM_GET` / `TLM_PARAM` — tuning

PID gains, hop parameters, calibration values. Acknowledged, unlike control
packets — losing a gain change silently would be maddening. Refuse parameter
writes while armed, except for the small allowlist you actually need to tune
in flight.

### `TLM_LOG` — vehicle → host

High-rate log records, drained over USB serial. Do not attempt to stream 1 kHz
logs over ESP-NOW; buffer to a ring in RAM and dump after landing.

## Failsafe on link loss

The vehicle tracks `now - last_valid_command_us`:

| Elapsed | Response |
|---|---|
| > 150 ms | warn — status flag set, controller LED changes |
| > 300 ms | **`FAILSAFE`** — ignore stale input, level attitude, hold height |
| > 1 s | begin autonomous descent |
| touchdown | disarm |

Never fly on a stale command. A held-over tilt command with no one to cancel it
is a vehicle accelerating in a straight line into something. Zero the input,
level the attitude, and put it down.

If the vehicle is `HOPPING` when the link drops, **complete the current hop
cycle, then transition to `FLYING` and descend.** Cutting thrust mid-launch is
worse than finishing a hop that is already ballistic.

### Two links, two ways to lose the pilot (gamepad only)

With the gamepad, the command path is two hops — DS4 → dongle → vehicle — so
there are two independent places it can break, and the ladder above only sees
the second one. The DS4 → dongle hop can drop on its own: gamepad powered off,
walked out of ~10 m range, or a dead controller battery.

When that happens the dongle has lost its input, and the rule is the same one
that governs the whole system: **never keep streaming a command nobody is
holding.** The dongle must **not** repeat the last stick values — a frozen tilt
with no hand behind it is exactly the stuck-command hazard the failsafe exists
to prevent. Instead the dongle **stops emitting `CMD_CONTROL`**, which the
vehicle sees as ordinary command-stream loss and handles with the identical
150 ms → 300 ms → descend ladder. Reusing the vehicle's existing failsafe for a
controller-side failure is deliberate: one well-tested safety path, not two.

The dongle should also flag "gamepad lost" to the ground station so you can see
*which* hop broke — but it does not need to tell the vehicle anything special.
Silence is already the correct signal.

### Pairing

ESP-NOW has no discovery or advertisement to secure — a device simply
registers a peer MAC with `esp_now_add_peer()` and can then send to it, so the
binding has to be enforced explicitly:

- Store the counterpart's MAC address in NVS on each side. On boot, register
  **only** that MAC as a peer.
- Reject any incoming frame whose source MAC doesn't match the bound peer,
  even though ESP-NOW will hand you the sender's address on every receive
  callback — don't skip this check because "only the vehicle is listening."
  Anything on the same channel can send an ESP-NOW frame; there is no
  connection state stopping it.
- An explicit pairing gesture (e.g. hold `SEL` at boot) is required to learn a
  new peer MAC. Never auto-bind to the first sender seen.
- Optional hardening: ESP-NOW supports per-peer AES-CTR encryption
  (`esp_now_set_pmk` / a per-peer LMK). Worth adding once the unencrypted link
  is proven, cheap enough that there's little reason not to.

This costs almost nothing and removes an entire category of accident — a
second controller, or another ESP-NOW device entirely, being able to command
the vehicle.

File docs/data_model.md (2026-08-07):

# Data model

The structs in `firmware/include/core/types.h` are the shared vocabulary
between modules. They carry **no logic and no hardware knowledge** — plain data
only. Every module compiles against that header, so changing a contract here is
a deliberate, cross-cutting decision.

Rules that keep this useful:

- Plain, trivially-copyable aggregates. No virtuals, no heap, no `std::string`.
- Explicit units in every field name or comment. `_m`, `_rad`, `_us`, `_v`.
- Every sample carries a `timestamp_us` and a `valid` flag. Consumers check
  both. An unchecked stale sample is indistinguishable from a fresh one, and
  that is how a vehicle flies into the ground on a reading from two seconds ago.
- Body frame unless a field says otherwise. Say otherwise loudly.

## Types

### `ImuData` — owner: IMU driver, consumer: estimator

Raw ICM-20948 sample.

| Field | Unit | Note |
|---|---|---|
| `timestamp_us` | µs | `micros()` at sample time, not at read time |
| `accel` | m/s² | body frame |
| `gyro` | rad/s | body frame |
| `mag` | µT | body frame; updates ~10× slower than accel/gyro |
| `mag_valid` | — | separate flag because of the rate mismatch |
| `temperature_c` | °C | optional |
| `valid` | — | false ⇒ failed read, treat as a timeout |

### `RangeData` — owner: ToF driver, consumer: estimator

One VL53L0X measurement. Two instances exist.

| Field | Unit | Note |
|---|---|---|
| `timestamp_us` | µs | |
| `distance_m` | m | **along the sensor boresight, not vertical** |
| `valid` | — | false ⇒ out of range, bad status, or stale |

The distinction between slant range and height is the source of most bugs in
this subsystem. The driver reports what the sensor measured; only the estimator
applies tilt compensation. See [estimator.md](estimator.md).

### `VehicleState` — owner: estimator, consumers: controller, hop sequencer, safety, telemetry

The single seam between sensing and control.

| Field | Unit | Note |
|---|---|---|
| `timestamp_us` | µs | time the estimate is valid for |
| `orientation` | quat | **authoritative** |
| `roll_rad`, `pitch_rad`, `yaw_rad` | rad | derived, for logging and limits |
| `angular_velocity` | rad/s | body frame, bias-corrected |
| `height_m` | m | above ground, tilt-compensated |
| `vertical_velocity_ms` | m/s | fused; required for apex detection |
| `ground_slope_rad` | rad | from the ToF pair's disagreement |
| `height_confidence` | enum | `NONE` / `INERTIAL` / `SINGLE` / `BOTH` |
| `ground_contact` | — | latched, debounced |
| `valid` | — | false ⇒ do not act on this |

`height_confidence` exists so consumers can make different decisions with
degraded data. Altitude hold needs `BOTH` or `SINGLE`; a hop can coast on
`INERTIAL` for a fraction of a second; nothing may act on `NONE`. Collapsing
this to a single boolean throws away the distinction that keeps a lost range
reading from becoming an emergency.

### `DesiredState` — owner: mode manager, consumer: controller

The vehicle-internal form of the pilot's intent. The mode manager builds it by
scaling the normalized `CMD_CONTROL` fields against the configured maxima and
**clamping** to the safety envelope — never by interpreting raw axes or a mode
byte, which no longer exist on the wire (see
[communication.md](communication.md)).

| Field | Unit | Note |
|---|---|---|
| `timestamp_us` | µs | |
| `roll_rad`, `pitch_rad` | rad | tilt setpoints, from `roll_cmd`/`pitch_cmd` × `max_tilt`, clamped |
| `yaw_rate_rads` | rad/s | **rate**, not angle; from `yaw_rate_cmd` × `max_yaw_rate` |
| `climb_rate_ms` | m/s | from `climb_rate_cmd` × `max_climb_rate` |
| `height_m` | m | hold target, integrated from climb rate against the height estimate |
| `thrust` | 0..1 | collective; **overridden by the hop sequencer** |
| `use_height_hold` | — | true whenever `climb_rate_cmd` rests at zero |

Yaw is a rate, not an angle, because absolute heading depends on a
magnetometer that is unreliable near loaded motors. Altitude is commanded as a
rate that integrates into a held height — which is what lets *any* controller,
one-stick or two, retrim altitude without ever having direct throttle
authority. This struct is essentially the decoded, unit-bearing, clamped form
of the `CMD_CONTROL` intent packet; keeping the wire packet's fields aligned
with it is deliberate, so there is one representation of "what the pilot
wants," not two that can drift.

### `ControlOutput` — owner: controller, consumer: mixer

| Field | Unit |
|---|---|
| `timestamp_us` | µs |
| `torque` | normalized −1..1 per axis |
| `thrust` | normalized 0..1 collective |

### `MotorOutput` — owner: mixer, consumers: safety then motor manager

| Field | Note |
|---|---|
| `timestamp_us` | |
| `count` | 4 |
| `value[4]` | normalized 0..1 |
| `saturated` | mixer hit a limit — controller freezes integrators |
| `armed` | |

`saturated` travels with the output because the controller needs it on the
*next* tick to suppress windup. Recomputing it elsewhere would duplicate the
mixer's allocation logic.

### `BatteryState` — owner: battery driver, consumers: safety, telemetry

| Field | Unit | Note |
|---|---|---|
| `timestamp_us` | µs | |
| `voltage_v` | V | **filtered** — raw sags hard on every launch burst |
| `voltage_raw_v` | V | unfiltered, logging only |
| `current_a` | A | 0 if not measured |
| `valid` | — | |

### `HopState` — owner: hop sequencer, consumers: controller, telemetry, logging

| Field | Note |
|---|---|
| `phase` | `STANCE` / `LAUNCH` / `ASCENT` / `APEX` / `DESCENT` |
| `phase_entered_us` | for timeouts and burst duration |
| `last_apex_height_m` | feeds height regulation |
| `hop_count` | |
| `abort_reason` | why the last hop ended early |

### `LinkStatus` — owner: link, consumers: safety, telemetry

| Field | Note |
|---|---|
| `last_rx_us` | the failsafe input |
| `connected` | |
| `rx_count`, `crc_errors`, `seq_gaps` | link quality |

### `Parameter`

Persisted in NVS: PID gains, hop timing and thrust, ToF geometry and leg
length, joystick calibration, failsafe thresholds, bound controller MAC.

Every parameter needs a compiled-in default, a min, and a max. Reject
out-of-range writes rather than clamping silently — a gain that got clamped
without telling you is a tuning session spent chasing nothing. Refuse writes
while armed except for a small explicit in-flight allowlist.

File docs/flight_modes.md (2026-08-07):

# Flight modes

Two orthogonal things are called "mode" and confusing them will cost you a
vehicle. Keep them separate — and note they live on **different processors**:

- **Vehicle state** — where the vehicle is in its lifecycle. Controls whether
  motors may spin. Lives on the **vehicle**. Changed by Safety, arming, and
  failsafes.
- **Control scheme** — how a given input device maps its sticks/buttons onto
  the four intent fields of `CMD_CONTROL`. Lives entirely on the
  **controller**. The vehicle has no knowledge of it — it only ever receives
  resolved intent (desired roll/pitch/yaw-rate/climb-rate). A control scheme
  **never affects whether the vehicle is armed.**

The rest of this document is split accordingly: the vehicle state machine is
firmware that runs on the aircraft; control schemes are firmware that runs on
whichever controller you built.

## Vehicle state machine

```
              BOOT
                │  hardware init
                ▼
          INITIALIZING ──────────────┐
                │  gyro bias, sensor │ any check fails
                │  checks, link up   │
                ▼                    ▼
           DISARMED  ◄────────────  FAULT
                │  ▲                     (requires power cycle)
     arm gesture│  │ disarm gesture
                ▼  │ or landed+idle
             ARMED ─┤
                │  ▲
   thrust raised│  │
                ▼  │
             FLYING ──────► HOPPING ──────┐
                │  ▲          │           │
                │  └──────────┘           │
        land cmd│                         │
                ▼                         │
             LANDING ──────► DISARMED     │
                                          │
   any state ──► FAILSAFE ◄───────────────┘
                    │  recoverable: auto-land
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

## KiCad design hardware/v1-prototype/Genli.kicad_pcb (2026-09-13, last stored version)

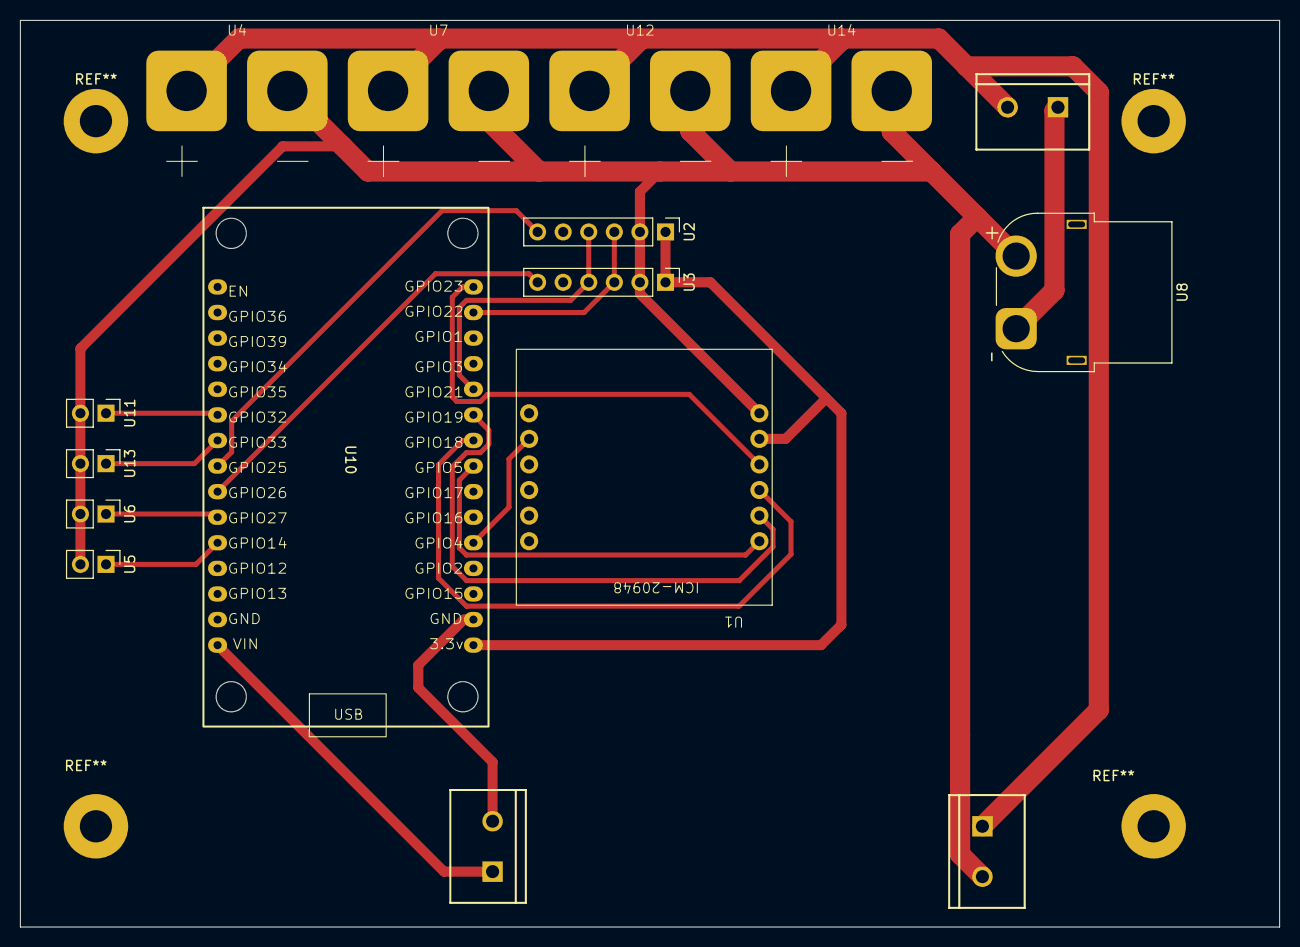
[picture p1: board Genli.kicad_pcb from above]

Board: 2 copper layers, 125.0 x 90.0 mm, 16 parts (0 on the bottom side), 19 nets.

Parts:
J1: Screw_Terminal_01x02; ScrewTerminal_1x02_P5.0mm
U1: ICM-20948; SEN-15335
U2, U3: VL53L0X; PinHeader_1x06_P2.54mm_Vertical
U4, U7, U12, U14: ESC_Power_SolderPads_1x02
U5, U6, U11, U13: PinHeader_1x02_P2.54mm_Vertical
U8: AMASS_XT60PW-F_1x02_P7.20mm_Horizontal
U9, U15: ScrewTerminal_1x02_P5.0mm
U10: ESP32_30pin

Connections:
/ESC1_SIG: U5.1 (SIGNAL), U10.5 (GPIO14)
/ESC2_SIG: U6.1 (SIGNAL), U10.6 (GPIO27)
/ESC3_SIG: U10.9 (GPIO33), U13.1 (SIGNAL)
/ESC4_SIG: U10.10 (GPIO32), U11.1 (SIGNAL)
/ESP_3.3V: U1.5 (VIN), U2.1 (VCC), U3.1 (VCC), U10.16 (3.3v)
/GND: U1.6 (GND), U2.2 (GND), U3.2 (GND), U4.2 (BAT-), U5.2 (GND), U6.2 (GND), U7.2 (BAT-), U8.2 (BAT-), U9.2 (VIN-), U11.2 (GND), U12.2 (BAT-), U13.2 (GND), U14.2 (BAT-)
/I2C_SCL: U2.3 (SCL), U3.3 (SCL), U10.29 (GPIO22)
/I2C_SDA: U2.4 (SDA), U3.4 (SDA), U10.26 (GPIO21)
/IMU_CS: U1.1 (CS), U10.23 (GPIO5)
/IMU_INT: U1.11 (INT), U10.20 (GPIO4)
/IMU_MISO: U1.2 (MISO), U10.25 (GPIO19)
/IMU_MOSI: U1.4 (MOSI), U10.30 (GPIO23)
/IMU_SCLK: U1.3 (SCLK), U10.24 (GPIO18)
/TOF1_XSHUT: U2.6 (XSHUT), U10.8 (GPIO25)
/TOF2_XSHUT: U3.6 (XSHUT), U10.7 (GPIO26)
/VBAT: J1.2, U4.1 (BAT+), U7.1 (BAT+), U9.1 (VIN+), U12.1 (BAT+), U14.1 (BAT+)
unnamed: J1.1, U8.1 (BAT+)
unnamed: U10.1 (VIN), U15.1 (5V)
unnamed: U10.17 (GND), U15.2 (GND)

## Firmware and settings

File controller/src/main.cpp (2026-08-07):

#include <Arduino.h>
#include "link/protocol.h"

using namespace revali::link;

void setup() {
    Serial.begin(115200);
    CmdControl cmd;  // default-constructed, all neutral
    Serial.println("Revali controller starting...");
    Serial.printf("CmdControl wire size=%u bytes, request=%d\n",
                  (unsigned)sizeof(cmd), cmd.request);
}

void loop() {}

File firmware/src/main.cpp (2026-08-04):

#include <Arduino.h>
#include "estimator/IStateEstimator.h"
#include "drivers/IImuSource.h"

using namespace revali;

void setup() {
    Serial.begin(115200);
    VehicleState s;              // default-constructed, all zeros
    Serial.println("Revali hopcopter FC starting...");
    Serial.printf("state valid=%d yaw=%.2f height=%.2f contact=%d\n",
                  s.valid, s.yaw_rad, s.height_m, s.ground_contact);
}

void loop() {}

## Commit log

2026-07-13 add flight_modes doc, data_model doc, and current tasks doc. Also narrow down objectives
2026-08-04 Remap project from robosub to hopcopter
    Strip the dual-vehicle (hopcopter/robosub) abstraction and retarget the
    firmware and docs solely at the hopcopter: ESP32-WROOM, ICM-20948 IMU,
    dual downward VL53L0X, quad-X pusher-prop airframe with a passive
    spring leg, and an offboard ESP32 joystick controller linked over
    ESP-NOW.
    - New docs: hardware.md (wiring, SPI-vs-I2C, ToF addressing/FOV,
    pusher-prop geometry), hop_mode.md (phase machine, thrust profile,
    prop-clearance tilt limit), safety.md (failsafe table, arming
    preconditions), ground_station.md (browser telemetry dashboard,
    per-arm-cycle session logging).
    - Rewrote architecture, communication, control_loop, data_model,
    estimator,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
    [main.cpp, types.h]
2026-08-07 Carry pilot intent on the wire; add gamepad controller path
    Refactor the control link so CMD_CONTROL carries resolved intent
    (roll/pitch/yaw-rate/climb-rate) rather than raw axes plus a mode byte.
    The vehicle becomes controller-agnostic: it scales incoming intent
    against its own maxima and clamps, so every physical/safety limit stays
    onboard and adding a controller type never touches flight-critical code.
    - Axis-mode cycling is now a controller-side concept (one-stick joystick
    cycles TILT/HEADING/ALTITUDE to fill four fields; a two-stick gamepad
    fills them directly, no modes). Vehicle no longer knows about modes;
    dropped axis_mode from TLM_STATE.
    - Split HOP_TOGGLE into explicit idemp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
2026-08-07 Add Phase 0 scaffolding: shared protocol, controller project, native tests
    - shared/link/protocol.h: the wire contract both projects build against
    (CmdControl, TlmState, ControlRequest/VehicleState/HopPhase wire
    enums, CRC-16/CCITT-FALSE), matching the intent-packet design in
    communication.md. Plain C++17, no Arduino dependency.
    - controller/: new PlatformIO project mirroring firmware/'s layout, for
    the reference joystick controller and the future DS4 dongle.
    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
2026-09-13 Document board architecture and the staged path to a custom FC
    Add docs/hardware_roadmap.md, the design-rationale companion to hardware.md.
    It records the decision to build the vehicle as two boards -- an off-the-shelf
    4-in-1 ESC carrying all motor current, and a custom FC carrying only
    signal-level electronics -- rather than a single custom board with integrated
    power distribution.
    The reasoning is mostly current, not voltage: the buck draws ~0.4 A from VBAT
    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
2026-09-13 Record the KO50A interface, power topology, and the switch decision
    The 4-in-1 and the 5 V regulator are ordered: Skystars KO50A and a Pololu
    D24V10F5. Document the ESC interface now that it is confirmed rather than
    assumed -- 8-pin JST-SH as GND, BAT, S1-S4, NC, CURR, with no BEC, so the 5 V
    rail is ours to generate.
    Two consequences worth writing down. BAT is raw pack voltage (16.8 V at full
    charge on 4S), so it reaches the buck input and the battery divider and nothing
    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
2026-09-13 Add CLAUDE.md and the Stage 2 carrier board specification
    Two additions supporting a split between the firmware and hardware tracks.
    CLAUDE.md carries what is true for any session in this repo: that docs/ is the
    source of truth and which doc is authoritative for what, the build and test
    commands, the standing rules, and the decisions that are settled -- ESP-NOW for
    this hardware generation, ADC1 only because the WiFi radio kills ADC2, and
    motor current never reaching our board.
    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
2026-09-13 Defer current sensing; add protection and defensive design to the carrier board
    Current sensing is now explicitly deferred rather than pending. The trace and
    footprints stay -- one trace and two pads on a board being made anyway, against
    a respin if it is later wanted -- but R3 is unpopulated, the net is open, and
    there is nothing to measure or calibrate at bring-up. Voltage sensing, which
    the low-battery failsafe actually requires, is unaffected.
    Add a protection section covering the things that are cheap now and a respin
    later. The most important is not electrical: two 1x15 sockets are mechanically
    symmetric, so a devkit inserted 180 degrees puts +5V on GND and destroys it
    instantly, and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
2026-09-13 Bring the KiCad work into the repo and vendor its libraries
    The v1 board lived in a separate repository with its symbol library referenced
    by an absolute path into OneDrive/Documents -- outside the project folder, so
    not committed anywhere. A clone of that repo could not resolve its own
    symbols. Its ESP32 devkit symbol and footprint came from a separately
    downloaded library that was likewise not committed.
    Archive v1 as hardware/v1-prototype/ (a snapshot -- its history stays in
    eli-lame/Genli, which is now frozen) and vendor every non-stock library under
    hardware/lib/, registered per project with ${KIPRJMOD}-relative paths rather
    than installed globally. Library nicknames are kept exactly a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
    [Genli.kicad_pcb, Genli.kicad_sch]
2026-09-13 Move the KiCad work to the Genli repository
    Boards live in eli-lame/Genli; this repository keeps firmware and all design
    documentation. The hardware/ tree added earlier is removed here and now lives
    there, restructured as one KiCad project per board with every non-stock library
    vendored.
    The docs stay here in full rather than following the boards across. They are
    heavily cross-linked -- hardware.md to safety.md to current_devtasks.md to
    estimator.md -- and splitting a few out would break those links at a repository
    boundary.
    That split does mean the schematic and the pin map can drift, so two rules are
    recorded: docs/hardware.md remains the sole pin map and Genli links to it
    rather than co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
    [Genli.kicad_pcb, Genli.kicad_sch]
2026-09-18 Record two VL53L0X carrier details that are invisible until they bite
    The breakout schematic shows its I2C pull-ups connect to VIN rather than to a
    regulated rail, so SDA and SCL sit at whatever VIN is. The board accepts 5 V
    happily -- it has its own regulator and a MOSFET level shifter -- but feeding
    it 5 V puts 5 V on GPIO 21 and 22, which are not 5 V tolerant. The pin map's
    3V3 entry for ToF VCC was already correct; this records that it is a hard
    requirement rather than a convention.
    Those same pull-ups also settle the carrier board question: two breakouts on
    one bus give ~5 kilohm in parallel, so no pull-ups are needed on our board.
    Second, XSHUT is pulled up by 47 kilohm to the breako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
2026-09-20 Add the reserved ELRS pins to the vehicle pin map
    GPIO 16 and 17 carry the Stage 2 board's reserved CRSF footprint, so they
    belong in the table that is the source of truth for GPIO assignments rather
    than only in the board spec.
    Records the direction explicitly, because the names are ambiguous and the
    mistake is invisible for months: GPIO 16 is the FC's transmit and goes to the
    receiver's RX; GPIO 17 is the FC's receive. Nothing is populated and no
    firmware should assume a receiver is present -- the link is ESP-NOW for this
    hardware generation.
    Also notes that these pins are not fixed by hardware. The ESP32 routes UART
    through its GPIO matrix, so any output-capable pin works; 16 and 17 are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
2026-09-20 Keep the arming buzzer on the Stage 2 board
    Reverts the not-fitted note. The buzzer stays; only ELRS moved.
2026-09-20 Move IMU INT from GPIO 4 to GPIO 35
    The interrupt line is only ever an input, so spending one of the input-only
    pins on it costs nothing and frees GPIO 4 as a full-function pin. The ESP32
    supports external interrupts on any usable GPIO, so input-only is no obstacle.
    Two consequences for firmware. GPIO 34-39 have no internal pull-up or
    pull-down and it is not configurable, which is fine while the ICM-20948's INT
    output stays push-pull -- its default -- but means an open-drain configuration
    would need an external pull-up that this board has no pad for. And the pin
    floats until the IMU initialises and starts driving it, so the interrupt
    handler must be attached after init or startup noise prod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
2026-09-21 Swap IMU SCLK to GPIO 25 and ToF A XSHUT to GPIO 18
    Done for layout: it puts the two ToF XSHUT lines on opposite pin rows of the
    devkit, matching their connectors being on opposite edges of the Stage 2 board.
    The consequence firmware must not miss is that GPIO 25 is not a VSPI default,
    so the SPI pins have to be named explicitly -- SPI.begin(25, 19, 23, 5). A bare
    SPI.begin() would drive GPIO 18 as the clock, which now resets a ToF instead,
    and the IMU would silently never respond.
    The cost is nil. SPI signals on non-default pins route through the GPIO matrix
    rather than the IOMUX, capping the bus at 40 MHz instead of 80 and adding about
    25 ns of input delay on MISO; this bus runs at 7 MHz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
2026-09-21 Swap IMU SCLK and MISO: SCLK to GPIO 19, MISO to GPIO 25
    Another layout-driven trade. It costs nothing: the bus left the IOMUX when SCLK
    first moved off GPIO 18, so every SPI signal was already routed through the GPIO
    matrix and shuffling further between non-default pins changes neither the
    40 MHz ceiling nor the ~25 ns MISO input delay. Both are irrelevant at 7 MHz.
    The risk is entirely in bookkeeping, so the note now spells out the argument
    order explicitly -- SPI.begin(19, 25, 23, 5), where 19 is the clock and 25 is
    MISO. Transposing those two puts the clock on the IMU's data-out line and the
    IMU never answers, which presents as a dead sensor rather than a firmware
    assumption.
    Co-Author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
2026-09-21 Sync the pin map to the routed Stage 2 board
    Five assignments changed during layout: IMU CS 5 to 15, SCLK 19 to 23, MOSI 23
    to 19, and I2C SDA and SCL swapped to 22 and 21. GPIO 4 and 5 are now both free.
    The consequence worth carrying is that **every** SPI pin and **both** I2C pins
    are now off their framework defaults, so bare SPI.begin() or Wire.begin() calls
    will silently use the wrong ones -- the default clock lands on GPIO 18, which
    now resets a ToF, and the default I2C assignment has SDA and SCL crossed. In
    neither case does anything error; the sensors simply never answer, which reads
    as dead hardware rather than a firmware assumption. The explicit calls and the
    argument orders are re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
2026-09-21 Record the Stage 2 board as built
    Outline came out at 58 x 88 mm -- bigger than a conventional FC because a
    30-pin devkit is 52 x 25 mm on its own, so the board overhangs the ESC on every
    side. Acceptable at this stage; Stage 3 shrinks it by dropping the devkit.
    Also records that ground is a single plane on B.Cu with no top pour, and why:
    the top layer routed densely enough that a pour filled only in patches and was
    not reaching several of the pads it was meant to serve. Every ground connection
    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
